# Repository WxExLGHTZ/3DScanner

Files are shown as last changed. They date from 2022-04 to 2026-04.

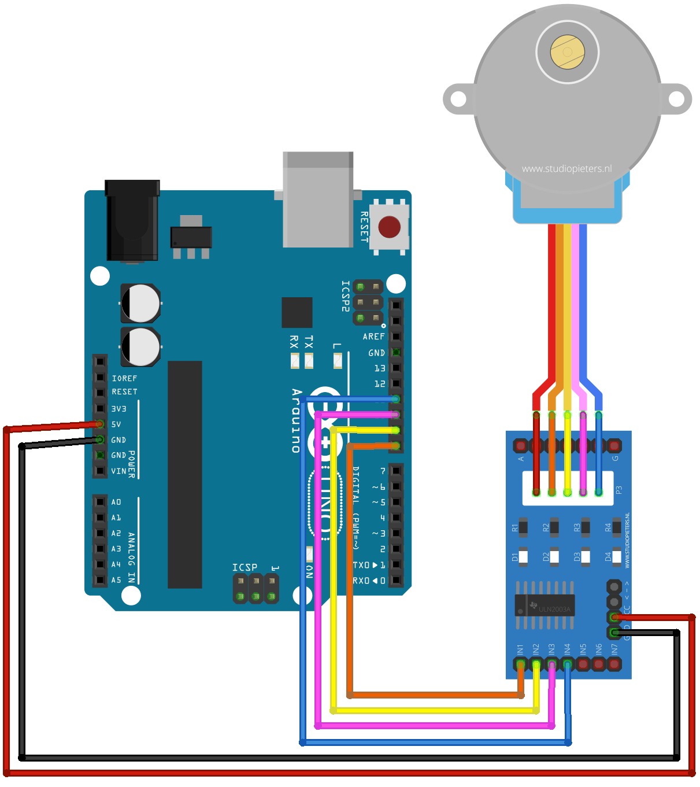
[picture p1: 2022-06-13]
Hardware/Arduino_Steckplan.jpeg

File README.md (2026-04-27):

# 3D Scanner

A desktop application that turns an Intel RealSense depth camera and an Arduino-driven stepper motor turntable into a 3D scanner — capturing RGBD frames from multiple angles, registering them into a unified point cloud via computed rotation-translation matrices, and reconstructing a watertight mesh exported as STL.

## Motivation

Building a 3D scanner from consumer hardware requires solving several non-trivial problems: synchronizing camera capture with turntable rotation, transforming each depth frame into world coordinates based on the current angle, and merging multiple partial point clouds into a single consistent model. This project handles the full pipeline — from raw RGBD frames captured by an Intel RealSense camera through multi-angle point cloud registration to Poisson surface reconstruction — controlled through a PyQt5 desktop interface that lets users configure scan resolution, mesh quality, and hardware settings.

## Features

- Scans physical objects by rotating them on an Arduino-controlled turntable while capturing RGBD frames from an Intel RealSense camera
- Registers point clouds from multiple viewing angles using computed rotation-translation matrices derived from the turntable geometry
- Crops, filters, and denoises point clouds with bounding box constraints and statistical outlier removal
- Reconstructs a watertight triangle mesh from the merged point cloud using Poisson surface reconstruction
- Exports the final model as an STL file, scaled to millimeters
- Displays the point cloud and mesh in an interactive 3D viewer (Open3D)
- Imports existing PLY point cloud files for viewing
- Provides configurable scan parameters: Arduino COM port, step size, frame resolution, and mesh quality settings

## Tech Stack

| Category | Technology |
|---|---|
| Language | Python 3.8.x |
| 3D Processing | Open3D (point clouds, meshing, visualization) |
| Depth Camera | Intel RealSense SDK (pyrealsense2) |
| GUI | PyQt5 |
| Motor Control | Arduino via pyserial (9600 baud) |

## Architecture

The system follows a capture-process-export pipeline driven by the turntable's rotation cycle. The **Arduino** firmware accepts step commands over serial and drives a stepper motor through a 6:1 gear reduction. The **InitializeScan** module configures the RealSense pipeline for aligned color and depth streams and extracts the camera intrinsics. At each rotation step, an RGBD frame is captured and handed to the **ProcessData** module, which converts it to an Open3D point cloud, computes the camera's extrinsic position from the current turntable angle (using trigonometric transformation with known distance and tilt offsets), applies the rotation-translation matrix, crops to a bounding box, and removes outliers. The partial clouds are accumulated into a single registered point cloud. After a full 360° rotation, the **ExportScan** module generates a bottom surface via convex hull sampling, then runs Poisson surface reconstruction with configurable depth and smoothing iterations to produce the final STL mesh.

```
Arduino Turntable ──► RealSense RGBD Capture ──► Point Cloud Conversion
    ──► Extrinsic Transform (angle-based) ──► Registration ──► Poisson Reconstruction ──► STL Export
```

## Getting Started

### Prerequisites

- Windows 
- Python 3.8.x (tested with 3.8.0)
- PyCharm or Visual Studio Code (recommended)
- Intel RealSense D400 series camera
- Arduino with stepper motor (28BYJ-48 + ULN2003 driver, pins 8–11)

### Hardware Setup

Connect the stepper motor driver to Arduino pins 8, 9, 10, 11 and upload the firmware:

```
Upload 3D_scan_neu.ino (or arduino_platform.ino) via the Arduino IDE.
```

> [!NOTE]
> A wiring diagram is provided in `Arduino_Steckplan.jpeg`.

### Installation

1. Clone the repository:
   ```bash
   git clone https://github.com/<your-username>/3d-scanner.git
   cd 3d-scanner/Software
   ```

2. Create and activate a virtual environment:
   ```bash
   python -m venv venv
   .\venv\Scripts\activate
   ```

3. Upgrade pip and install dependencies:
   ```bash
   python -m pip install --upgrade pip
   pip install -r requirements.txt
   ```

> [!NOTE]
> macOS users need to install pyrealsense2 from a separate source:
> `pip install pyrealsense2 -f https://github.com/cansik/pyrealsense2-macosx/releases`

4. Open the project in PyCharm or VS Code and set the interpreter to `venv/Scripts/Python.exe`.

## Usage

1. Place the object on the turntable and connect both the Arduino and the RealSense camera.
2. Run the application:
   ```bash
   python main.py
   ```
3. Click **Settings** to configure the Arduino COM port (default: `COM5`) and scan parameters.
4. Click **Start Scan** — the turntable rotates in steps while the camera captures frames. The status bar shows the current angle. The scan takes less than 1 minute.
5. Click **Show Pointcloud** to inspect the registered point cloud in the 3D viewer.
6. Click **Save STL** to reconstruct the mesh and export it as an STL file.

Alternatively, use **Import** to load an existing `.ply` point cloud file for viewing.

## Authors

- William Eppel
- Mert Karadeniz
- Vinh Thong Trinh
- Habib Ben Khedher

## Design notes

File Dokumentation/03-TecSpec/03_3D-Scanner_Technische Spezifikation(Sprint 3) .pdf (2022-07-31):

### Technische Spezifikation 3D-Scanner mit einer Intel Realsense

© HTW Berlin

# Technische Spezifikation

# HTW Berlin 3D-Scanner mit einer Intel Realsense

Autoren: | Mert Karadeniz, Vinh Thong Trinh, Habib Ben Khedher, William Eppel
Letzte Änderung: 31. Juli 2022
Dateiname: | 03_3D-Scanner_Technische Spezifikation
Version: | 3.0

© HTW Berlin

Copyright

© Mohammad Abuosba

Die Weitergabe, Vervielfältigung oder anderweitige Nutzung dieses Dokumentes oder Teile davon ist unabhängig vom Zweck oder in welcher Form untersagt, es sei denn, die Rechteinhaber/In hat ihre ausdrückliche schriftliche Genehmigung erteilt.

Version Historie

Version | Datum | Verantwortlich | Änderung
1.0 | 02.06.2022 | Alle | Ordnung der Aufgabenbereiche
1.1 | 03.06.2022 | Alle | Einfügung von gegebenen Diagrammen
1.2 | 04.06.2022 | Alle | Systeminfrastruktur
1.3 | 07.06.2022 | Vinh, William | Workflow überarbeitet
1.4 | 07.06.2022 | Mert, Habib | Konstruktion Tech spec.
1.5 | 10.06.2022 | Alle | Konstruktion Tech spec., Beschreibung der Imple-mentierungen überarbeitet
2.0 | 10.06.2022 | Alle | Rechtschreibung, Grammatik
2.1 | 07.07.2022 | Alle | Berichtigung der gegeben Fehler
2.2 | 08.07.2022 | Alle | Hinzufügen neuer Funktionen
2.4 | 11.07.2022 | Alle | Neue Konstruktionszeichnungen eingefügt
3.0 | 31.07.2022 | Alle | Finalisierung

© HTW Berlin | Seite I

## Inhaltsverzeichnis

Abbildungsverzeichnis | II
Verzeichnis vorhandener Dokumente | III

© HTW Berlin | Seite II

## Abbildungsverzeichnis

© HTW Berlin | Seite III

## Verzeichnis vorhandener Dokumente

Alle für die vorliegende Spezifikation ergänzenden Unterlagen müssen hier aufgeführt werden.

Dokument | Autor | Datum
Lastenheft_3d-Scanner.pdf | Team 3 | 25.04.2022
02 Muster_Pflichtenheft.pdf | Team 3 | 23.05.2022
FÜP_SS22.mpp | Team 3 | 23.05.2022

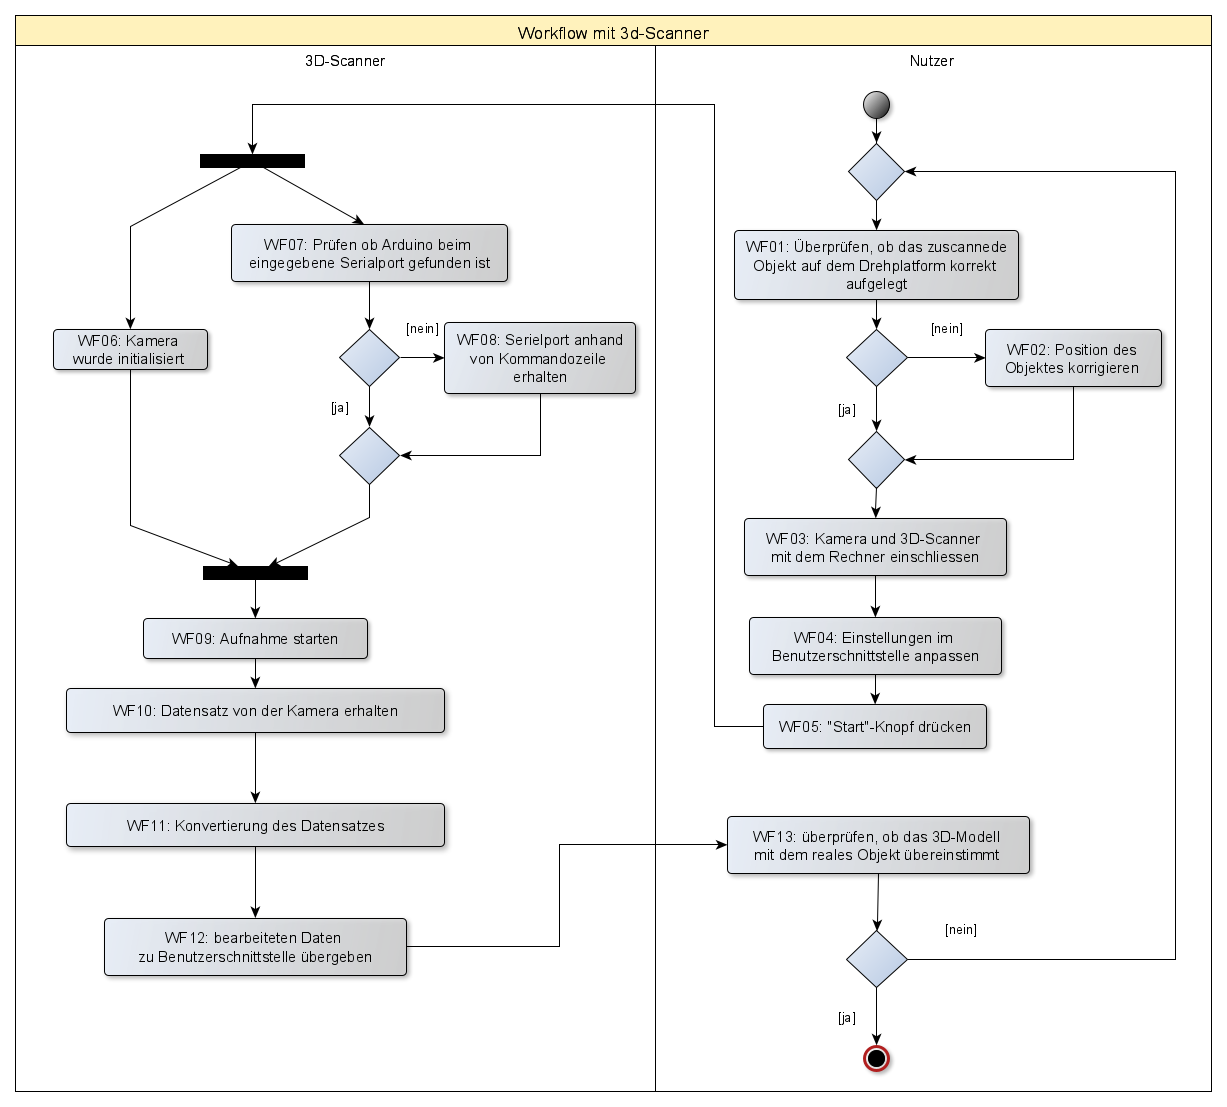
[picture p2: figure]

© HTW Berlin | Seite 1

## 1 Prozessüberblick

## 1.1 Fachlicher Workflow

Im Folgenden wird der fachliche Workflow des Systems dargestellt.

Abbildung 1: Fachlicher Workflow

## 1.2 Technischer Workflow

Im Folgenden wird der technische Workflow des Systems dargestellt.

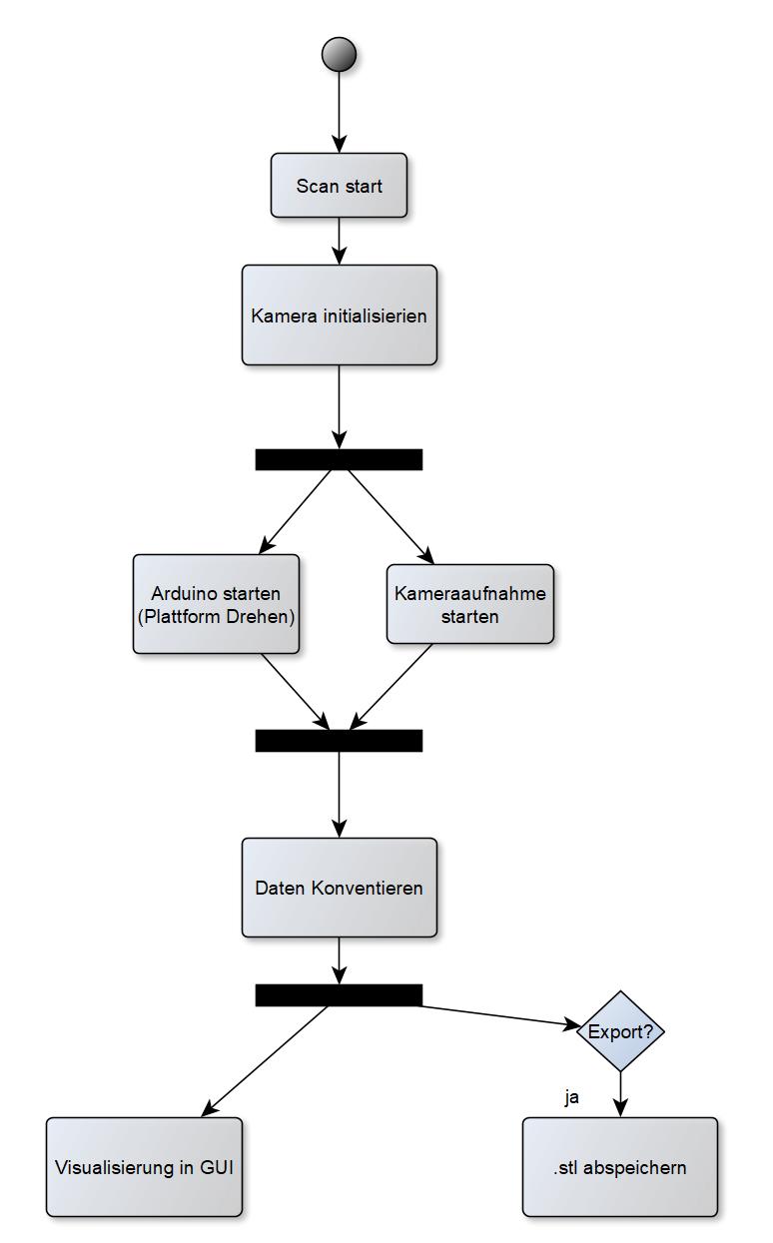
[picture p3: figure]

Abbildung 2: Grober technischer Workflow

Im folgenden wird der technische Workflow im Falle eines Fehlers dargestellt.

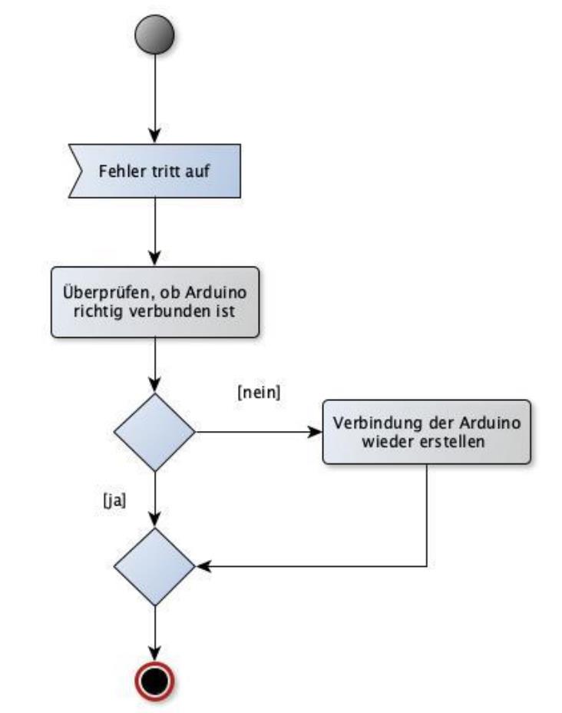
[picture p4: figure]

Abbildung 3: Fehler technischer Workflow

## 2 Technische Spezifikation SW 2.1 Überblick Komponenten

Im folgenden Komponentendiagramm werden die Komponenten der Software dargestellt.

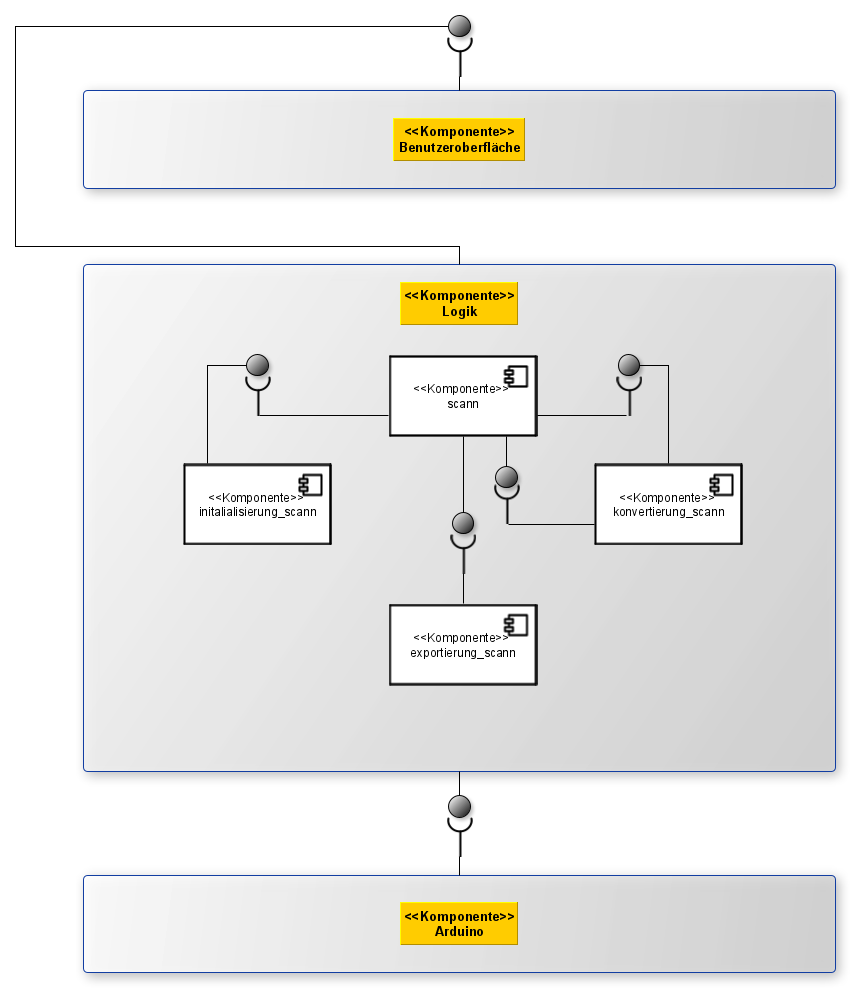
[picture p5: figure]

Abbildung 4: Komponentendiagramm

In der folgenden Tabelle werden die Komponenten ihren Funktionen zugeordnet.

SW-Komponente | Erfasste Funktion aus dem Pflichtenheft
Benutzeroberfläche | F7: Einstellungen Anpassen F8: Standarteinstellungen zurücksetzen UI Funktionen: UI02: Start Scan UI03: Stop Scan UI04: Import UI05: Export UI06: Einstellungen UI07: Beenden UI08: Hilfe
scann | F1: Objekt scannen
Initialiserung_scann | F2: Initialisierung der Kamera F3: Kommunikation mit Arduino F4: Kameraaufnahme starten
konvertierung_scann | F5: Konvertierung/Verarbeitung der Daten
exportierung_scann | F9: Exportierung des Scans als .stl Datei F6: Abspeichern des Scans
Arduino | F10: Rotation des Stepper Motors

Im Folgenden werden die Klassen des Systems in einem Klassendiagramm dargestellt.

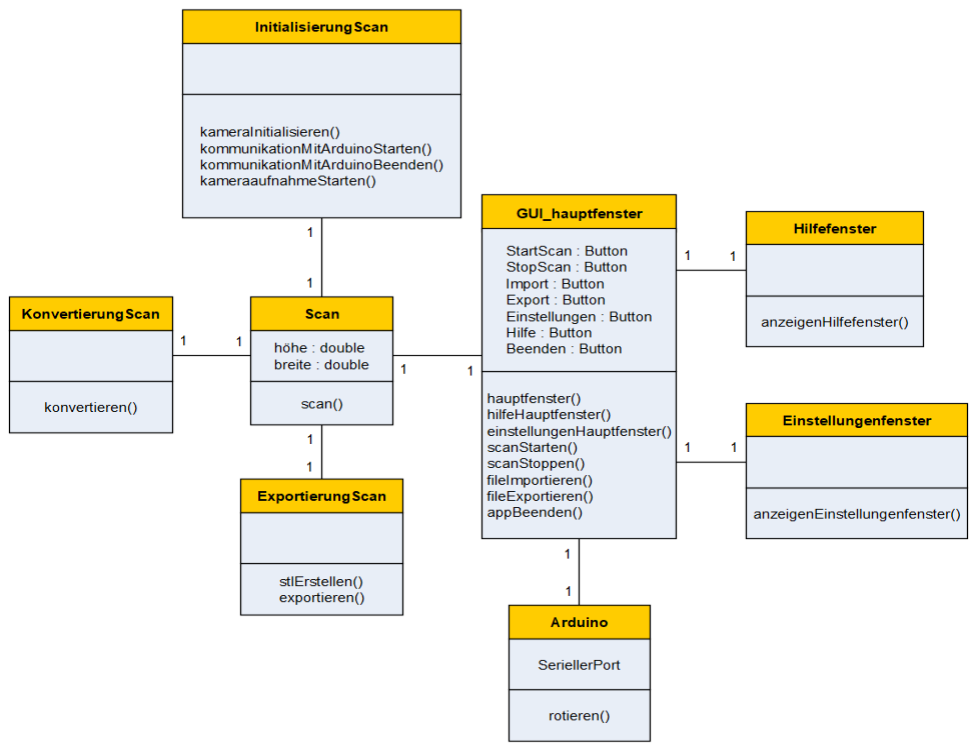
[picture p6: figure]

Abbildung 5: Klassendiagramm

## 2.2 Beschreibung der Implementierung

## 2.2.1 Objekt scannen

Durch die Funktion Objekt scannen, kann ein Scan des Objekts gemacht und daraus ein 3D-Modell erstellt werden.

# | Komponentendetail | Erforderliche Arbeiten

T1 | GUI | • Die Funktion “Scan” soll über den Knopf “Start Scan” ge- startet werden
T2 | Logik | • Die Kamera soll Initialisiert werden • Die Kommunikation mit dem Arduino soll aufgebaut wer-den • Die Kameraaufnahme soll gestartet werden • Die aufgenommenen Daten sollen Konvertiert werden • Das Modell soll erstellt werden
T3 | Arduino | • Nach jedem aufgenommenen Bild soll sich der Schrittmo-tor, der an den Arduino angeschlossen ist, um eine Posi-tion weiterdrehen

## 2.2.2 Kamera initialisieren

Durch die Funktion “Kamera initialisieren” soll die Kamera angeschaltet werden. Es wird geprüft ob eine Kommunikation mit der Kamera besteht.

# | Komponentendetail | Erforderliche Arbeiten

T2 | Logik | • Die Kamera wird eingeschaltet • Die Kommunikation mit der Kamera wird geprüft

## 2.2.3 Drehplattform durch GUI steuern

Durch die Funktion “Drehplattform durch GUI steuern” soll eine Verbindung zwischen der Anwendung und dem Arduino hergestellt werden.

# | Komponentendetail | Erforderliche Arbeiten

T2 | Logik | • Kommunikation mit Arduino soll aufgebaut und überprüft werden
T3 | Arduino | • Arduino wird gestartet

## 2.2.4 Kameraaufnahme starten

Durch die Funktion “Kameraaufnahme starten” sollen mithilfe der Kamera Aufnahmen erstellt werden die anschließend weiterverarbeitet werden sollen.

# | Komponentendetail | Erforderliche Arbeiten

T2 | Logik | • Die Kamera soll in bestimmten Abständen Aufnahmen machen • Die Aufnahmen werden zwischengespeichert

## 2.2.5 Konvertierung der Daten

Durch diese Funktion werden die aufgenommenen Datensätze der Kamera verarbeitet, um sie verwenden zu können.

# | Komponentendetail | Erforderliche Arbeiten

T2 | Logik | • Die Funktion kriegt die aufgenommenen Daten und wan-delt sie in verwendbare Daten um • Die Daten bestehen aus Tiefenbildern die wichtigen Infor-mationen beinhalten • Der entstandene verwendbare Datensatz wird zur GUI weitergegeben • Die Konvertierung der aufgenommenen Datensätze muss implementiert werden

## 2.2.6 Gescanntes Objekt exportieren

Der Scan wird im gewünschten Ort des Nutzers abgespeichert für eine mögliche Weiterverwendung.

# | Komponentendetail | Erforderliche Arbeiten

T1 | GUI | • Die Funktion “Abspeichern des Scans” soll über den Knopf “Export” gestartet werden
T2 | Logik | • Nachdem die Konvertierung zur .stl Datei stattgefunden hat soll die in einem gewünschten Bereich des Nutzers ab-gespeichert werden

## 2.2.7 Einstellungen anpassen

Durch die Funktion “Einstellungen anpassen” können Einstellungen angepasst werden.

# | Komponentendetail | Erforderliche Arbeiten

T1 | GUI | • Die Einstellungen sollen durch die GUI geändert werden

## 2.2.8 Standardeinstellungen zurücksetzen

Die Funktion setzt das Programm wieder auf Werkseinstellungen zurück.

# | Komponentendetail | Erforderliche Arbeiten

T1 | GUI | • Durch einen Knopf in der GUI soll die Funktion “Standar-teinstellungen zurücksetzen” ausgeführt werden • Dadurch werden die Einstellungen zurückgesetzt sowie sie vom Werk aus waren

## 2.2.9 Im Format .stl abspeichern

Das 3D-Model wird in eine .stl Datei konvertiert.

# | Komponentendetail | Erforderliche Arbeiten

T2 | Logik | • In dieser Funktion wird das aufgenommene 3D-Mo-del in eine .stl Datei konvertiert • Durch die Konvertierung in .stl ist eine Weiterverwendung des Models möglich • Die Funktion erhaltet eine Punktwolke und konvertiert diese in .stl

## 2.2.10 Rotation des Steppermotors

Diese Funktion beinhaltet die Rotation des Steppermotors um die Plattform sich rotieren zu lassen.

# | Komponentendetail | Erforderliche Arbeiten

T3 | Arduino | • | Der Arduino spricht den Steppermotor an und lässt ihn in bestimmten Zeit- und Winkelabständen rotieren

## 2.2.11 Portcheck_Arduino

Diese Funktion beinhaltet den Check ob eine Verbindung zu einem Arduino Mikroprozessor besteht.

# | Komponentendetail | Erforderliche Arbeiten

T3 | Logik | • Die Logik versucht einen Arduino anzusprechen, bzw. gibt alle verbundenen Arduinos aus.

## 2.2.12 Portcheck_Cam

Diese Funktion beinhaltet den Check ob eine Verbindung zu einem Realsense Kamera besteht.

# | Komponentendetail | Erforderliche Arbeiten

T3 | Logik | • Die Logik versucht die Realsense Kamera anzuspre-chen und checkt somit ob eine Verbindung besteht

## 2.2.13 Import File

Die Funktion “Import File” bietet die Möglichkeit gegebene .ply Dateien in die GUI zur Ansicht importieren.

# | Komponentendetail | Erforderliche Arbeiten

T3 | GUI | • Durch die GUI wird ein Fenster mit der ausgewählten Datei eröffnet indem man sich das Bauteil anschauen kann

## 2.2.14 Statusmessage

Die Funktion “Statusmessage” ändert die Statusmeldung in der Statusbar, um den User auf dem Laufenden zu halten.

# | Komponentendetail | Erforderliche Arbeiten

T3 | GUI | • Anzeigen der veränderten Statusmeldung.

## 2.3 System Infrastruktur

Die Infrastruktur des Systems besteht aus 4 Komponenten. Der User ist dafür zuständig die Hardware und Software vorzubereiten zum Start, außerdem muss der User die gewünschten Aufforderungen durch die GUI in der Software geben. Die Software nimmt die Aufforderungen des Users an und führt sie aus, dazu ist meist auch eine Kommunikation mit der Hardware nötig, um gegebenenfalls das Drehen der Plattform zu starten. Die Kamera kriegt durch die Software die Anforderungen in bestimmten Abständen Fotos zu schießen, diese werden dann auch zurückgeleitet an die Software.

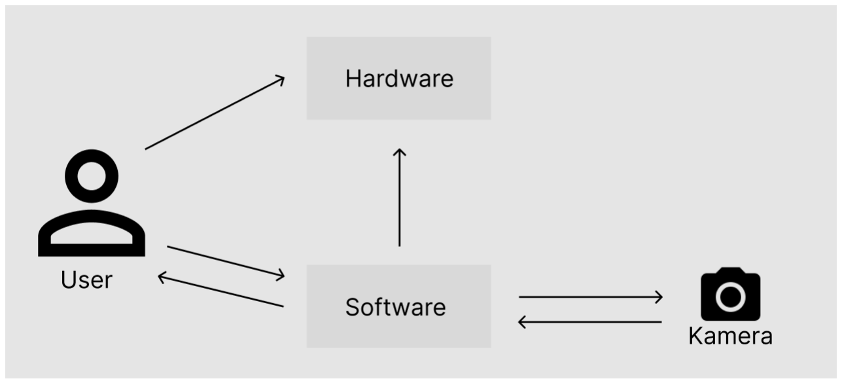
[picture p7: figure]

Abbildung 6: Systeminfrastruktur

## 3 Technische Spezifikation Konstruktion

## 3.1 Baugruppen

Die Baugruppe “3D_Scanner” besteht aus 7 Bauteilen; Gehäuse, Drehplattform Kamerahalter, Zahnrad, Lager, Verbindungsstück und Drehlager. Sie ist die einzige Baugruppe der Konstruktion und ist somit der Hauptbestandteil der Konstruktion. Sie bietet eine Halterung für die Kamera somit die Kamera immer richtig auf das Objekt gerichtet ist, solange das Objekt nicht die Maße des maximal scannbaren Objekts überschreitet. Die Drehplattform befindet sich auf dem Gehäuse, diese bietet eine Fläche für die Platzierung des Objekts. Das Gehäuse bietet Stauplatz für die Hardware und außerdem ist sie auch der Fuß der Konstruktion. Das Verbindungsstück besteht aus Holz und ist die Verbindung zwischen Gehäuse und Kamerahalter, Sie bietet die optimale Distanz von Kamera zum Gehäuse. Das Lager hält das Drehlager und wird im Zentrum des Gehäuses mit zwei Schrauben festgeschraubt. Das Drehlager wird genau zwischen Lager und Plattform platziert somit das Drehlager mit beiden Bauteilen verbunden ist, dadurch wird die Rotation der Plattform ermöglicht. Das Zahnrad wird auf dem Steppermotor platziert, damit es die Drehung auf die Plattform übertragen kann.

Abbildung 7: Technische Zeichnung - Baugruppen

## 3.2 Einzelteile

### Drehplattform

Die Drehplattform ist die Plattform, worauf sich das zu scannende Objekt platziert wird. Die Plattform kann auch als Deckel zum Gehäuse betrachtet werden. Sie dient sowohl als Schutz zur Hardware als auch zur Rotation des Objektes. Sie wird durch eine Kerbe im in der Mitte an den Stepper Motor befestigt.

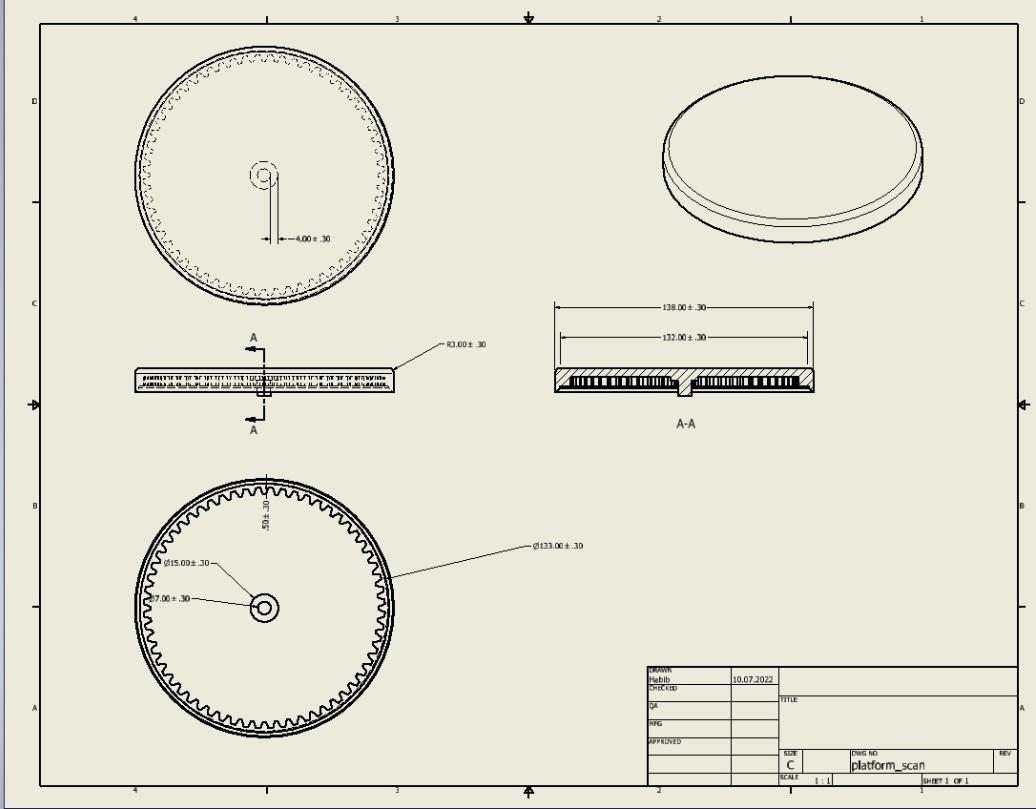
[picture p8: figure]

Abbildung 8: Technische Zeichnung - Drehplattform

### Gehäuse

Das Gehäuse ist der Fuß der Konstruktion. Sie enthält Staufläche für die Hardware und ist auch der Verbindungspunkt aller Bauteile in der Konstruktion. Das Gehäuse bietet einen Verbindungspunkt für die Kamerahalterung durch eine Öffnung an der Wand Seite. Die Hardware wird innerhalb des Gehäuses so platziert, sodass der Motor direkt in die Kerbe der Drehplattform eingeführt werden kann.

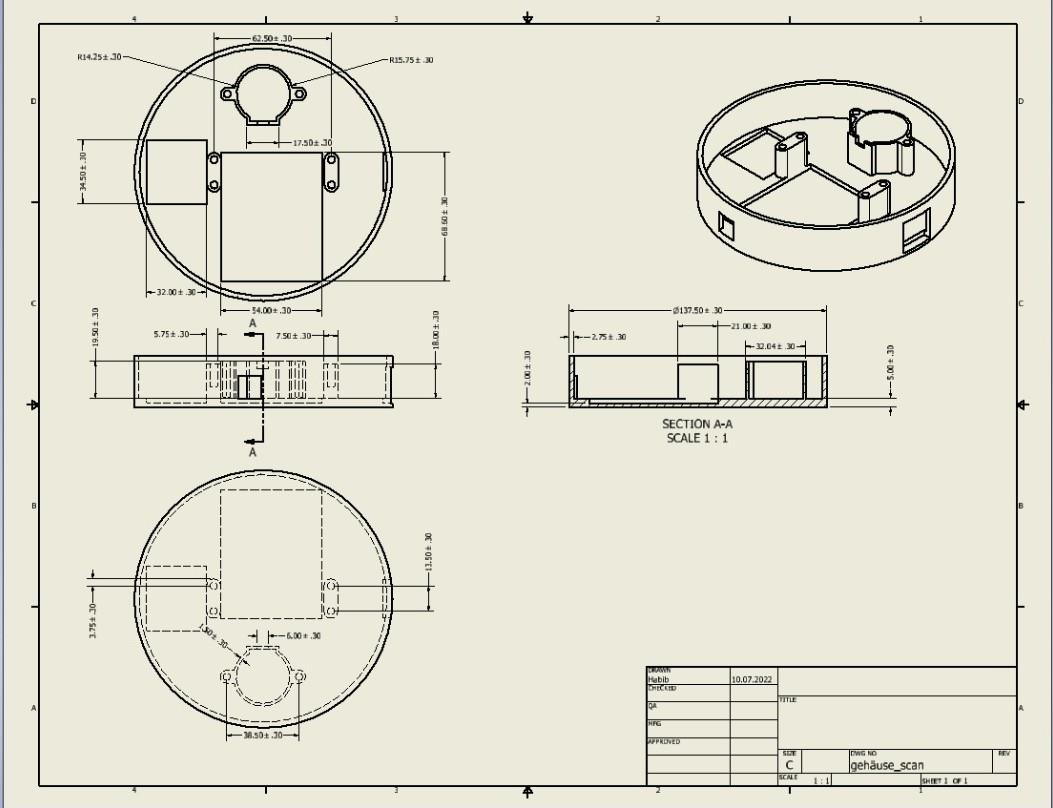
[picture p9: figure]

Abbildung 9: Technische Zeichnung - Gehäuse

### Kamerahalter

Der Kamerahalter ist dazu da die Kamera zu halten. Außerdem ist der Kamerahalter die Verbindung zwischen Kamera und Gehäuse. Durch den Kamerahalter befindet sich die Kamera immer an der optimalen Stelle. Der Kamerahalter wird durch die Öffnung in der Gehäusen Wand eingeführt. Die Kamera wird auf der Spitze des Kamerahalters durch eine Schraube befestigt.

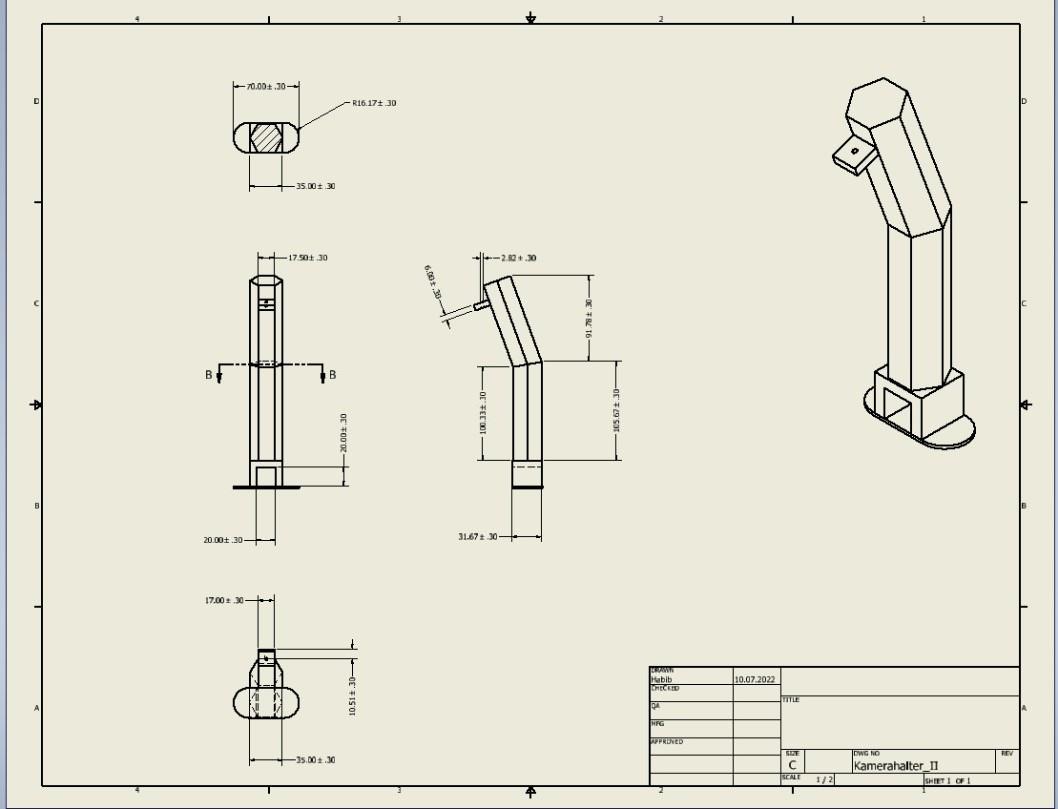
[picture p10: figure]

Abbildung 10: Technische Zeichnung - Kamerahalter

### Lager

Das Lager befindet sich im Gehäusezentrum und bietet eine Verbindung zur Plattform. Durch das Lager wird sie mit der Plattform verbunden und durch zwei Schrauben mit dem Gehäuse. Durch diese Verbindung kann sich die Plattform rotieren und ist dennoch mit dem Gehäuse verbunden. Sie bietet somit auch eine Verschließung der Hardware innerhalb des Gehäuses.

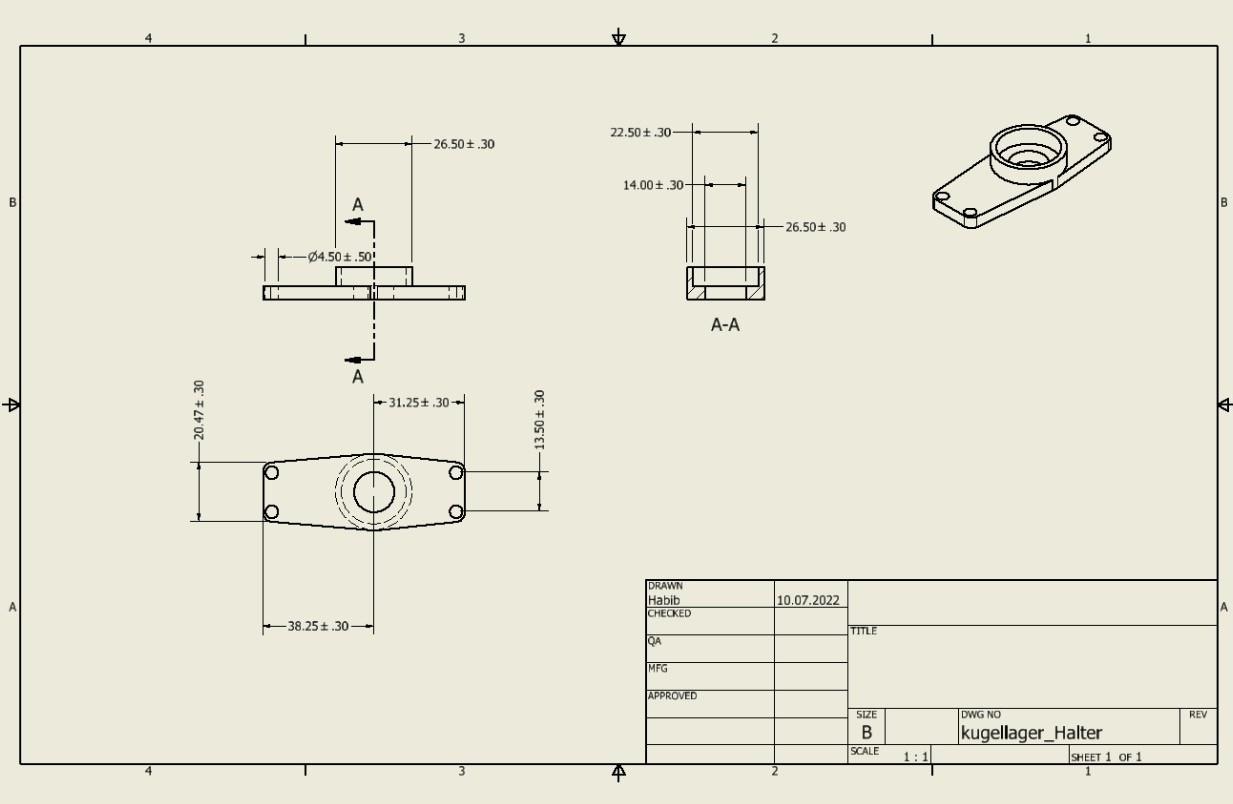
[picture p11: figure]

### Zahnrad

Das Zahnrad befindet sich im Gehäuse auf dem Steppermotor. Sie grenzt am inneren Gewinde der Plattform und ist dadurch mit dem Steppermotor und der Plattform verbunden. Die Drehung des Steppermotors wird durch das Zahnrad auf die Plattform übertragen.

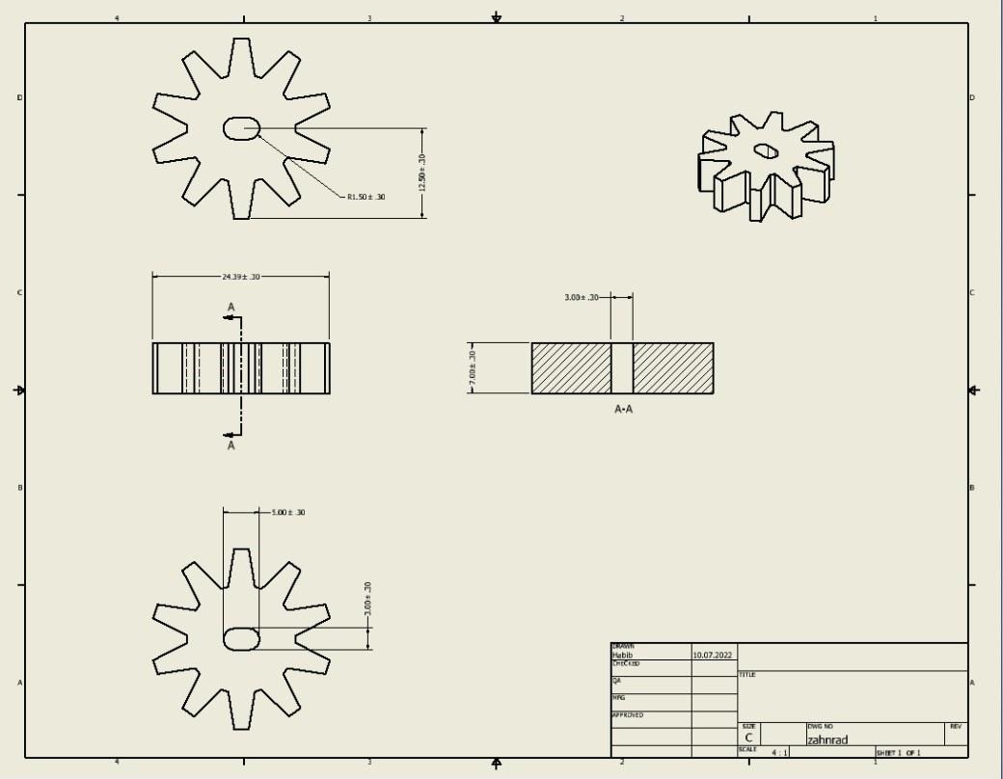
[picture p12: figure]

## 4 Offene Fragen

# | Issue | Status | Owner | Deadline

/ | / | / | / | /

## 5 Modul Abhängigkeiten

1. Programmierung: Die Software wird programmiert
2. Konstruktion: Es wird eine Plattform konstruiert um das Objekt draufzustellen
3. Mechatronik: Es wird ein Mikroprozessor zur Steuerung des Stepper Motors verwendet

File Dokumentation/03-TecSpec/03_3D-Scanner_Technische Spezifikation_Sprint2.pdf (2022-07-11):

### Technische Spezifikation 3D-Scanner mit einer Intel Realsense

© HTW Berlin

# Technische Spezifikation

# HTW Berlin 3D-Scanner mit einer Intel Realsense

Autoren: | Mert Karadeniz, Vinh Thong Trinh, Habib Ben Khedher, William Eppel
Letzte Änderung: 11. Juli 2022
Dateiname: | 03_3D-Scanner_Technische Spezifikation
Version: | 2.5

© HTW Berlin

Copyright

© Mohammad Abuosba

Die Weitergabe, Vervielfältigung oder anderweitige Nutzung dieses Dokumentes oder Teile davon ist unabhängig vom Zweck oder in welcher Form untersagt, es sei denn, die Rechteinhaber/In hat ihre ausdrückliche schriftliche Genehmigung erteilt.

Version Historie

Version | Datum | Verantwortlich | Änderung
1.0 | 02.06.2022 | Alle | Ordnung der Aufgabenbereiche
1.1 | 03.06.2022 | Alle | Einfügung von gegebenen Diagrammen
1.2 | 04.06.2022 | Alle | Systeminfrastruktur
1.3 | 07.06.2022 | Vinh, William | Workflow überarbeitet
1.4 | 07.06.2022 | Mert, Habib | Konstruktion Tech spec.
1.5 | 10.06.2022 | Alle | Konstruktion Tech spec., Beschreibung der Imple-mentierungen überarbeitet
2.0 | 10.06.2022 | Alle | Rechtschreibung, Grammatik
2.1 | 07.07.2022 | Alle | Berichtigung der gegeben Fehler
2.2 | 08.07.2022 | Alle | Hinzufügen neuer Funktionen
2.4 | 11.07.2022 | Alle | Neue Konstruktionszeichnungen eingefügt
2.5 | 11.07.2022 | Alle | Formatierung überarbeitet

© HTW Berlin | Seite I

## Inhaltsverzeichnis

Abbildungsverzeichnis | II
Verzeichnis vorhandener Dokumente | III

© HTW Berlin | Seite II

## Abbildungsverzeichnis

© HTW Berlin | Seite III

## Verzeichnis vorhandener Dokumente

Alle für die vorliegende Spezifikation ergänzenden Unterlagen müssen hier aufgeführt werden.

Dokument | Autor | Datum
Lastenheft_3d-Scanner.pdf | Team 3 | 25.04.2022
02 Muster_Pflichtenheft.pdf | Team 3 | 23.05.2022
FÜP_SS22.mpp | Team 3 | 23.05.2022


© HTW Berlin | Seite 1

## 1 Prozessüberblick

## 1.1 Fachlicher Workflow

Im Folgenden wird der fachliche Workflow des Systems dargestellt.

Abbildung 1: Fachlicher Workflow

## 1.2 Technischer Workflow

Im Folgenden wird der technische Workflow des Systems dargestellt.


Abbildung 2: Grober technischer Workflow

Im folgenden wird der technische Workflow im Falle eines Fehlers dargestellt.


Abbildung 3: Fehler technischer Workflow

## 2 Technische Spezifikation SW 2.1 Überblick Komponenten

Im folgenden Komponentendiagramm werden die Komponenten der Software dargestellt.


Abbildung 4: Komponentendiagramm

In der folgenden Tabelle werden die Komponenten ihren Funktionen zugeordnet.

SW-Komponente | Erfasste Funktion aus dem Pflichtenheft
Benutzeroberfläche | F7: Einstellungen Anpassen F8: Standarteinstellungen zurücksetzen UI Funktionen: UI02: Start Scan UI03: Stop Scan UI04: Import UI05: Export UI06: Einstellungen UI07: Beenden UI08: Hilfe
scann | F1: Objekt scannen
Initialiserung_scann | F2: Initialisierung der Kamera F3: Kommunikation mit Arduino F4: Kameraaufnahme starten
konvertierung_scann | F5: Konvertierung/Verarbeitung der Daten
exportierung_scann | F9: Exportierung des Scans als .stl Datei F6: Abspeichern des Scans
Arduino | F10: Rotation des Stepper Motors

Im Folgenden werden die Klassen des Systems in einem Klassendiagramm dargestellt.

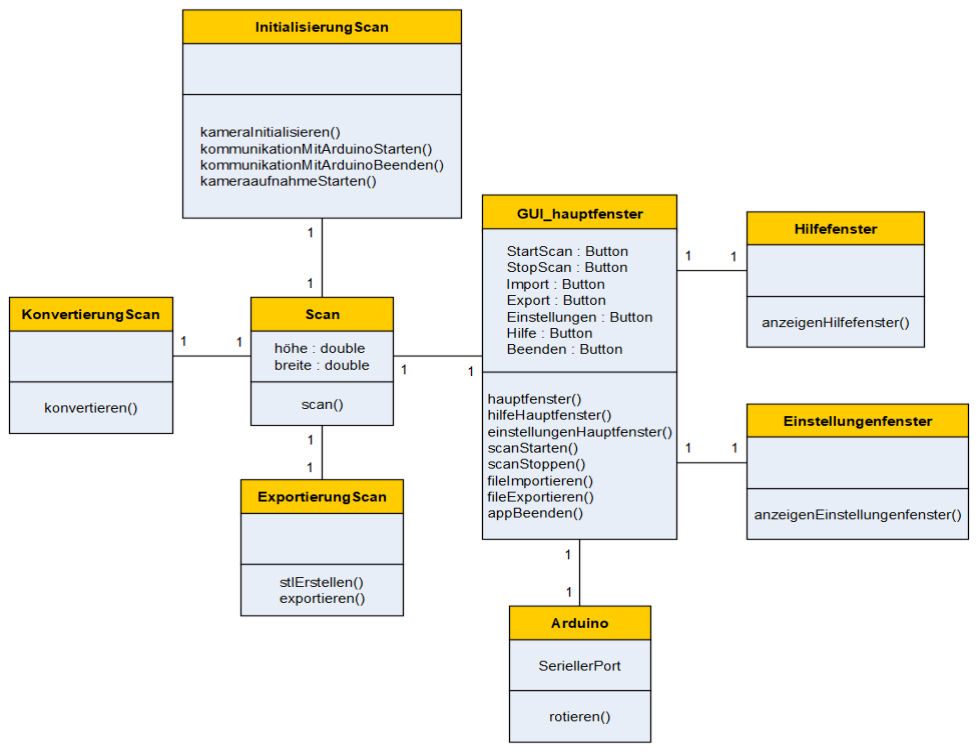
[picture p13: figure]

Abbildung 5: Klassendiagramm

## 2.2 Beschreibung der Implementierung

## 2.2.1 Objekt scannen

Durch die Funktion Objekt scannen, kann ein Scan des Objekts gemacht und daraus ein 3D-Modell erstellt werden.

# | Komponentendetail | Erforderliche Arbeiten

T1 | GUI | • Die Funktion “Scan” soll über den Knopf “Start Scan” ge- startet werden
T2 | Logik | • Die Kamera soll Initialisiert werden • Die Kommunikation mit dem Arduino soll aufgebaut wer-den • Die Kameraaufnahme soll gestartet werden • Die aufgenommenen Daten sollen Konvertiert werden • Das Modell soll erstellt werden
T3 | Arduino | • Nach jedem aufgenommenen Bild soll sich der Schrittmo-tor, der an den Arduino angeschlossen ist, um eine Posi-tion weiterdrehen

## 2.2.2 Kamera initialisieren

Durch die Funktion “Kamera initialisieren” soll die Kamera angeschaltet werden.
Es wird geprüft ob eine Kommunikation mit der Kamera besteht.
# | Komponentendetail | Erforderliche Arbeiten

T2 | Logik | • Die Kamera wird eingeschaltet • Die Kommunikation mit der Kamera wird geprüft

## 2.2.3 Drehplattform durch GUI steuern

Durch die Funktion “Drehplattform durch GUI steuern” soll eine Verbindung zwischen der Anwendung und dem Arduino hergestellt werden.

# | Komponentendetail | Erforderliche Arbeiten

T2 | Logik | • Kommunikation mit Arduino soll aufgebaut und überprüft werden
T3 | Arduino | • Arduino wird gestartet

## 2.2.4 Kameraaufnahme starten

Durch die Funktion “Kameraaufnahme starten” sollen mithilfe der Kamera Aufnahmen erstellt werden die anschließend weiterverarbeitet werden sollen.

# | Komponentendetail | Erforderliche Arbeiten

T2 | Logik | • Die Kamera soll in bestimmten Abständen Aufnahmen machen • Die Aufnahmen werden zwischengespeichert

## 2.2.5 Konvertierung der Daten

Durch diese Funktion werden die aufgenommenen Datensätze der Kamera verarbeitet, um sie verwenden zu können.

# | Komponentendetail | Erforderliche Arbeiten

T2 | Logik | • Die Funktion kriegt die aufgenommenen Daten und wan-delt sie in verwendbare Daten um • Die Daten bestehen aus Tiefenbildern die wichtigen Infor-mationen beinhalten • Der entstandene verwendbare Datensatz wird zur GUI weitergegeben • Die Konvertierung der aufgenommenen Datensätze muss implementiert werden

## 2.2.6 Gescanntes Objekt exportieren

Der Scan wird im gewünschten Ort des Nutzers abgespeichert für eine mögliche Weiterverwendung.

# | Komponentendetail | Erforderliche Arbeiten

T1 | GUI | • Die Funktion “Abspeichern des Scans” soll über den Knopf “Export” gestartet werden
T2 | Logik | • Nachdem die Konvertierung zur .stl Datei stattgefunden hat soll die in einem gewünschten Bereich des Nutzers ab-gespeichert werden

## 2.2.7 Einstellungen anpassen

Durch die Funktion “Einstellungen anpassen” können Einstellungen angepasst werden.

# | Komponentendetail | Erforderliche Arbeiten

T1 | GUI | • Die Einstellungen sollen durch die GUI geändert werden

## 2.2.8 Standardeinstellungen zurücksetzen

Die Funktion setzt das Programm wieder auf Werkseinstellungen zurück.

# | Komponentendetail | Erforderliche Arbeiten

T1 | GUI | • Durch einen Knopf in der GUI soll die Funktion “Standar-teinstellungen zurücksetzen” ausgeführt werden • Dadurch werden die Einstellungen zurückgesetzt sowie sie vom Werk aus waren

## 2.2.9 Im Format .stl abspeichern

Das 3D-Model wird in eine .stl Datei konvertiert.

# | Komponentendetail | Erforderliche Arbeiten

T2 | Logik | • In dieser Funktion wird das aufgenommene 3D-Mo-del in eine .stl Datei konvertiert • Durch die Konvertierung in .stl ist eine Weiterverwendung des Models möglich • Die Funktion erhaltet eine Punktwolke und konvertiert diese in .stl

## 2.2.10 Rotation des Steppermotors

Diese Funktion beinhaltet die Rotation des Steppermotors um die Plattform sich rotieren zu lassen.

# | Komponentendetail | Erforderliche Arbeiten

T3 | Arduino | • Der Arduino spricht den Steppermotor an und lässt ihn in bestimmten Zeit- und Winkelabständen rotieren

## 2.2.11 Portcheck_Arduino

Diese Funktion beinhaltet den Check ob eine Verbindung zu einem Arduino Mikroprozessor besteht.

# | Komponentendetail | Erforderliche Arbeiten

T3 | Logik | • Die Logik versucht einen Arduino anzusprechen, bzw. gibt alle verbundenen Arduinos aus.

## 2.2.12 Portcheck_Cam

Diese Funktion beinhaltet den Check ob eine Verbindung zu einem Realsense Kamera besteht.

# | Komponentendetail | Erforderliche Arbeiten

T3 | Logik | • Die Logik versucht die Realsense Kamera anzuspre-chen und checkt somit ob eine Verbindung besteht

## 2.2.13 Import File

Die Funktion “Import File” bietet die Möglichkeit gegebene .ply Dateien in die GUI zur Ansicht importieren.

# | Komponentendetail | Erforderliche Arbeiten

T3 | GUI | • Durch die GUI wird ein Fenster mit der ausgewählten Datei eröffnet indem man sich das Bauteil anschauen kann

## 2.3 System Infrastruktur

Die Infrastruktur des Systems besteht aus 4 Komponenten. Der User ist dafür zuständig die Hardware und Software vorzubereiten zum Start, außerdem muss der User die gewünschten Aufforderungen durch die GUI in der Software geben. Die Software nimmt die Aufforderungen des Users an und führt sie aus, dazu ist meist auch eine Kommunikation mit der Hardware nötig, um gegebenenfalls das Drehen der Plattform zu starten. Die Kamera kriegt durch die Software die Anforderungen in bestimmten Abständen Fotos zu schießen, diese werden dann auch zurückgeleitet an die Software.

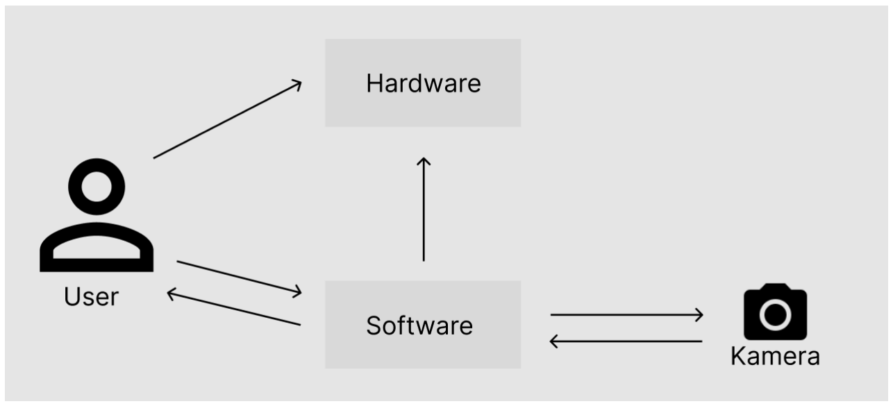
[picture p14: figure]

Abbildung 6: Systeminfrastruktur

## 3 Technische Spezifikation Konstruktion

## 3.1 Baugruppen

Die Baugruppe “3D_Scanner” besteht aus 7 Bauteilen; Gehäuse, Drehplattform Kamerahalter, Zahnrad, Lager, Verbindungsstück und Drehlager. Sie ist die einzige Baugruppe der Konstruktion und ist somit der Hauptbestandteil der Konstruktion. Sie bietet eine Halterung für die Kamera somit die Kamera immer richtig auf das Objekt gerichtet ist, solange das Objekt nicht die Maße des maximal scannbaren Objekts überschreitet. Die Drehplattform befindet sich auf dem Gehäuse, diese bietet eine Fläche für die Platzierung des Objekts. Das Gehäuse bietet Stauplatz für die Hardware und außerdem ist sie auch der Fuß der Konstruktion. Das Verbindungsstück besteht aus Holz und ist die Verbindung zwischen Gehäuse und Kamerahalter, Sie bietet die optimale Distanz von Kamera zum Gehäuse. Das Lager hält das Drehlager und wird im Zentrum des Gehäuses mit zwei Schrauben festgeschraubt. Das Drehlager wird genau zwischen Lager und Plattform platziert somit das Drehlager mit beiden Bauteilen verbunden ist, dadurch wird die Rotation der Plattform ermöglicht. Das Zahnrad wird auf dem Steppermotor platziert, damit es die Drehung auf die Plattform übertragen kann.

## 3.2 Einzelteile

### Drehplattform

Die Drehplattform ist die Plattform, worauf sich das zu scannende Objekt platziert wird. Die Plattform kann auch als Deckel zum Gehäuse betrachtet werden. Sie dient sowohl als Schutz zur Hardware als auch zur Rotation des Objektes. Sie wird durch eine Kerbe im in der Mitte an den Stepper Motor befestigt.


Abbildung 7: Technische Zeichnung - Drehplattform

### Gehäuse

Das Gehäuse ist der Fuß der Konstruktion. Sie enthält Staufläche für die Hardware und ist auch der Verbindungspunkt aller Bauteile in der Konstruktion. Das Gehäuse bietet einen Verbindungspunkt für die Kamerahalterung durch eine Öffnung an der Wand Seite. Die Hardware wird innerhalb des Gehäuses so platziert, sodass der Motor direkt in die Kerbe der Drehplattform eingeführt werden kann.


Abbildung 8: Technische Zeichnung - Gehäuse

### Kamerahalter

Der Kamerahalter ist dazu da die Kamera zu halten. Außerdem ist der Kamerahalter die Verbindung zwischen Kamera und Gehäuse. Durch den Kamerahalter befindet sich die Kamera immer an der optimalen Stelle. Der Kamerahalter wird durch die Öffnung in der Gehäusen Wand eingeführt. Die Kamera wird auf der Spitze des Kamerahalters durch eine Schraube befestigt.


Abbildung 9: Technische Zeichnung - Kamerahalter

### Lager

Das Lager befindet sich im Gehäusezentrum und bietet eine Verbindung zur Plattform. Durch das Lager wird sie mit der Plattform verbunden und durch zwei Schrauben mit dem Gehäuse. Durch diese Verbindung kann sich die Plattform rotieren und ist dennoch mit dem Gehäuse verbunden. Sie bietet somit auch eine Verschließung der Hardware innerhalb des Gehäuses.


Abbildung 10: Technische Zeichnung - Kugellagerhalter

### Zahnrad

Das Zahnrad befindet sich im Gehäuse auf dem Steppermotor. Sie grenzt am inneren Gewinde der Plattform und ist dadurch mit dem Steppermotor und der Plattform verbunden. Die Drehung des Steppermotors wird durch das Zahnrad auf die Plattform übertragen.


Abbildung 11: Technische Zeichnung - Zahnrad

## 4 Offene Fragen

# | Issue | Status | Owner | Deadline

/ | / | / | / | /

## 5 Modul Abhängigkeiten

1. Programmierung: Die Software wird programmiert
2. Konstruktion: Es wird eine Plattform konstruiert um das Objekt draufzustellen
3. Mechatronik: Es wird ein Mikroprozessor zur Steuerung des Stepper Motors verwendet

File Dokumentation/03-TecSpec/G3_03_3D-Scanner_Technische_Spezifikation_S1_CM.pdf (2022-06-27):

### Technische Spezifikation 3D-Scanner mit einer Intel Realsense

© HTW Berlin

# Technische Spezifikation

# HTW Berlin 3D-Scanner mit einer Intel Realsense

Autor: | Mert Karadeniz, Vinh Thong Trinh, Habib Ben Khedher, William Eppel
Letzte Änderung: 13. Juni 2022
Dateiname: | 03_3D-Scanner_Technische Spezifikation
Version: | 2.0

© HTW Berlin

Copyright

© Mohammad Abuosba

Die Weitergabe, Vervielfältigung oder anderweitige Nutzung dieses Dokumentes oder Teile davon ist unabhängig vom Zweck oder in welcher Form untersagt, es sei denn, die Rechteinhaber/In hat ihre ausdrückliche schriftliche Genehmigung erteilt.

Version Historie

Version | Datum | Verantwortlich | Änderung
1.0 | 02.06.2022 | Alle | Ordnung der Aufgabenbereiche
1.1 | 03.06.2022 | Alle | Einfügung von gegebenen Diagrammen
1.2 | 04.06.2022 | Alle | Systeminfrastruktur
1.3 | 07.06.2022 | Vinh, William | Workflow überarbeitet
1.4 | 07.06.2022 | Mert, Habib | Konstruktion Tech spec.
1.5 | 10.06.2022 | Alle | Konstruktion Tech spec., Beschreibung der Imple-mentierungen überarbeitet
2.0 | 10.06.2022 | Alle | Rechtschreibung, Grammatik
2.0 | 13.06.2022 | Alle | Finalisierung

© HTW Berlin

## Inhaltsverzeichnis

Abbildungsverzeichnis | I
Tabellenverzeichnis | II
Verzeichnis vorhandener Dokumente | III

© HTW Berlin | Seite I

## Abbildungsverzeichnis

© HTW Berlin | Seite II

## Tabellenverzeichnis

© HTW Berlin | Seite III

## Verzeichnis vorhandener Dokumente

Alle für die vorliegende Spezifikation ergänzenden Unterlagen müssen hier aufgeführt werden.

Dokument | Autor | Datum
Lastenheft_3d-Scanner.pdf | Team 3 | 25.04.2022
02 Muster_Pflichtenheft.pdf | Team 3 | 23.05.2022
FÜP_SS22.mpp | Team 3 | 23.05.2022

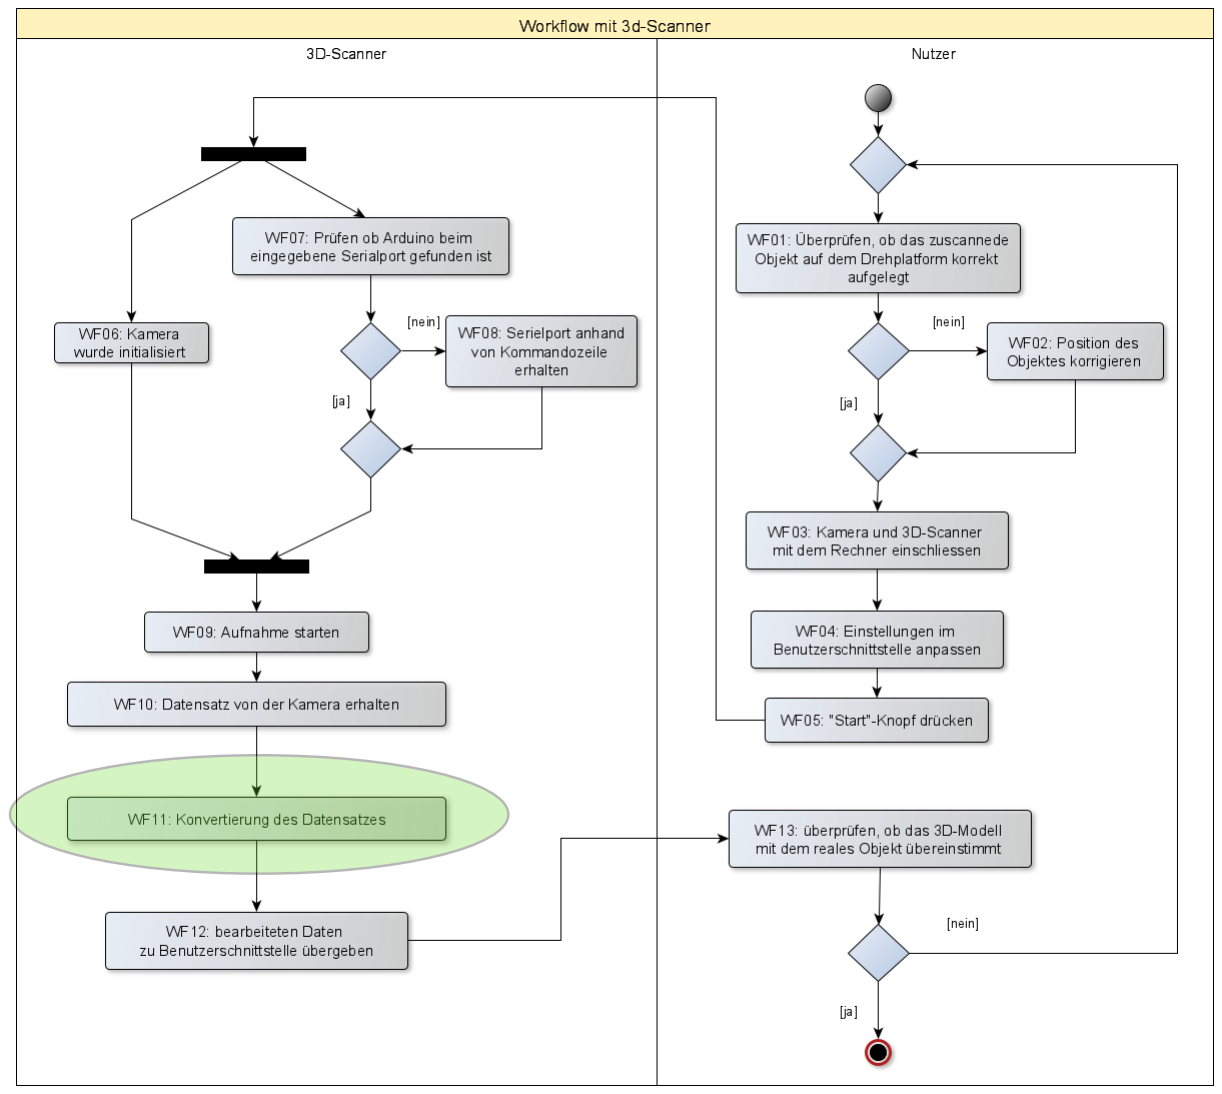
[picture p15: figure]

© HTW Berlin | Seite 1

## 1 Prozessüberblick

## 1.1 Fachlicher Workflow

Im Folgenden wird der fachliche Workflow des Systems dargestellt.

Abbildung 1: Fachlicher Workflow

## 1.2 Technischer Workflow

Im Folgenden wird der technische Workflow des Systems dargestellt.


Abbildung 2: Grober technischer Workflow

Im folgenden wird der technische Workflow im Falle eines Fehlers dargestellt.


Abbildung 3: Fehler technischer Workflow

## 2 Technische Spezifikation SW 2.1 Überblick Komponenten

Im folgenden Komponentendiagramm werden die Komponenten der Software dargestellt.


Abbildung 4: Komponentendiagramm

In der folgenden Tabelle werden die Komponenten ihren Funktionen zugeordnet.

SW-Komponente | Erfasste Funktion aus dem Pflichtenheft
Benutzeroberfläche | F7: Einstellungen Anpassen F8: Standarteinstellungen zurücksetzen UI Funktionen: UI01: 3D-Viewer UI02: Start Scan UI03: Stop Scan UI04: Import UI05: Export UI06: Einstellungen UI07: Beenden UI08: Hilfe
Scan | F1: Objekt scannen
Initialiserung_scan | F2: Initialisierung der Kamera F3: Kommunikation mit Arduino F4: Kameraaufnahme starten
Konvertierung_scan | F5: Konvertierung/Verarbeitung der Daten
Exportierung_scan | F9: Exportierung des Scans als .stl Datei F6: Abspeichern des Scans
Arduino | F10: Rotation des Stepper Motors

Tabelle 1: Zuordnung der Komponenten

Im Folgenden werden die Klassen des Systems in einem Klassendiagramm dargestellt.

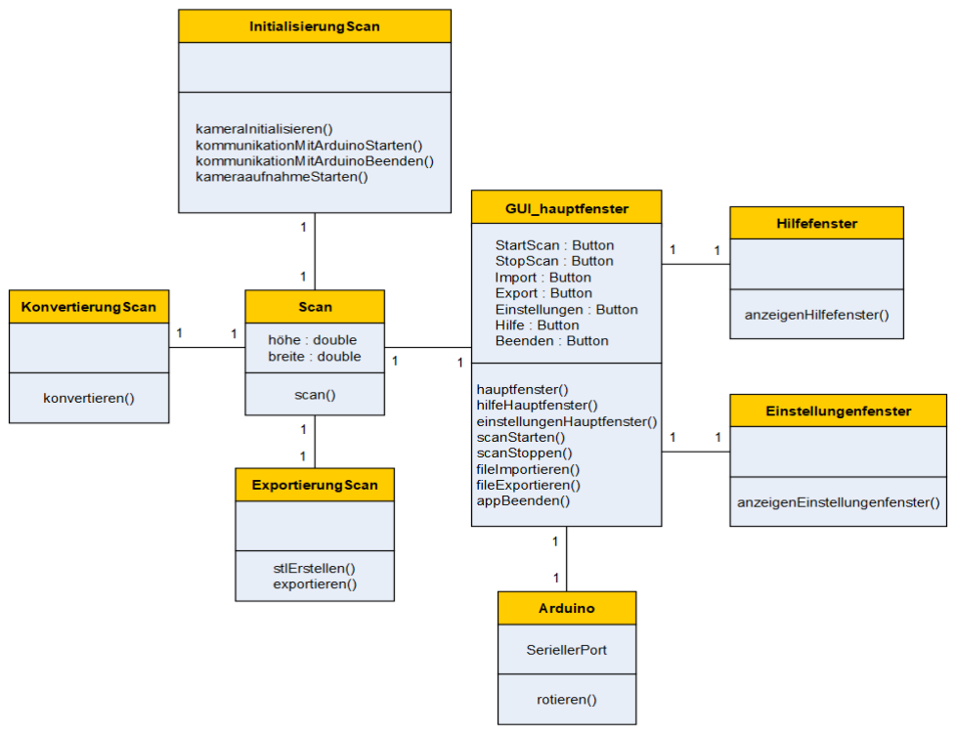
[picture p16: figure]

Abbildung 5: Klassendiagramm

## 2.2 Beschreibung der Implementierung

## 2.2.1 Scan

Durch die Funktion Scan, kann ein Scan des Objekts gemacht und daraus ein 3d-Modell erstellt werden.

# | Komponentendetail | Erforderliche Arbeiten

T1 | GUI | • Die Funktion “Scan” soll über den Knopf “StartScan” ge-startet werden
T2 | Logik | • Die Kamera soll Initialisiert werden • Die Kommunikation mit dem Arduino soll aufgebaut wer- den • Die Kameraaufnahme soll gestartet werden • Die aufgenommenen Daten sollen Konvertiert werden • Das Modell soll erstellt werden
T3 | Arduino | • Nach jedem aufgenommenen Bild soll sich der Schrittmo- tor, der an den Arduino angeschlossen ist, um eine Posi- tion weiterdrehen

Tabelle 2: Beschreibung von der Funktion „Scan“

## 2.2.2 Initialisierung der Kamera

Durch die Funktion “Kamera initialisieren” soll die Kamera angeschaltet werden. Es wird geprüft ob eine Kommunikation mit der Kamera besteht.

# | Komponentendetail | Erforderliche Arbeiten

T2 | Logik | • Die Kamera wird eingeschaltet • Die Kommunikation mit der Kamera wird geprüft

Tabelle 3: Beschreibung der Funktion „Kamera Initialisierung"

## 2.2.3 Kommunikation mit Arduino

Durch die Funktion “Kommunikation mit Arduino” soll eine Verbindung zwischen der Anwendung und dem Arduino hergestellt werden.

# | Komponentendetail | Erforderliche Arbeiten

T2 | Logik | • Kommunikation mit Arduino soll aufgebaut und überprüft werden
T3 | Arduino | • Arduino wird gestartet

Tabelle 4: Beschreibung von der Funktion "Kommunikation mit Arduino"

## 2.2.4 Kameraaufnahme starten

Durch die Funktion “Kameraaufnahme starten” sollen mithilfe der Kamera Aufnahmen erstellt werden die anschließend weiterverarbeitet werden sollen.

# | Komponentendetail | Erforderliche Arbeiten

T2 | Logik | • Die Kamera soll in bestimmten Abständen Aufnahmen machen • Die Aufnahmen werden zwischengespeichert

Tabelle 5: Beschreibung von der Funktion "Kameraaufnahme starten"

## 2.2.5 Konvertierung/Verarbeitung der Daten

Durch diese Funktion werden die aufgenommenen Datensätze der Kamera verarbeitet, um sie verwenden zu können.

# | Komponentendetail | Erforderliche Arbeiten

T2 | Logik | • Die Funktion kriegt die aufgenommenen Daten und wan-delt sie in verwendbare Daten um • Die Daten bestehen aus Tiefenbildern die wichtigen Infor-mationen beinhalten • Der entstandene verwendbare Datensatz wird zur GUI weitergegeben • Die Konvertierung der aufgenommenen Datensätze muss implementiert werden

Tabelle 6: Beschreibung der Funktion "Konvertierung der Daten"

## 2.2.6 Abspeichern des Scans

Der Scan wird im gewünschten Ort des Nutzers abgespeichert für eine mögliche Weiterverwendung.

# | Komponentendetail | Erforderliche Arbeiten

T1 | GUI | • Die Funktion “Abspeichern des Scans” soll über den Knopf “Export” gestartet werden
T2 | Logik | • Nachdem die Konvertierung zur .stl Datei stattgefunden hat soll die in einem gewünschten Bereich des Nutzers ab-gespeichert werden

Tabelle 7: Beschreibung von der Funktion "Abspeichern des Scans"

## 2.2.7 Einstellungen anpassen

Durch die Funktion Einstellungen anpassen können Einstellungen angepasst werden.

# | Komponentendetail | Erforderliche Arbeiten

T1 | GUI | • Die Einstellungen sollen durch die GUI geändert werden

Tabelle 8: Beschreibung der Funktion "Einstellungen Anpassen"

## 2.2.8 Standardeinstellungen zurücksetzen

Die Funktion führt das Programm wieder auf Werkseinstellungen.

# | Komponentendetail | Erforderliche Arbeiten

T1 | GUI | • Durch einen Knopf in der GUI soll die Funktion “Standar-teinstellungen zurücksetzen” ausgeführt werden • Dadurch werden die Einstellungen zurückgesetzt sowie sie vom Werk aus waren

Tabelle 9: Beschreibung von der Funktion "Standarteinstellungen zurücksetzen"

## 2.2.9 Exportierung des Scans in .stl Datei

Das 3D-Model wird in eine .stl Datei konvertiert.

# | Komponentendetail | Erforderliche Arbeiten

T2 | Logik | • In dieser Funktion wird das aufgenommene 3D-Mo-del in eine .stl Datei konvertiert • Durch die Konvertierung in .stl ist eine Weiterverwendung des Models möglich • Die Funktion erhaltet eine Punktwolke und konvertiert diese in .stl

Tabelle 10: Beschreibung der Funktion "Exportierung des Scans"

## 2.2.10 Rotation des Stepper Motors

Diese Funktion beinhaltet die Rotation des Stepper Motors um die Plattform sich rotieren zu lassen.

# | Komponentendetail | Erforderliche Arbeiten

T3 | Arduino | • Der Arduino spricht den Stepper Motor an und lässt ihn in bestimmten Zeit- und Winkelabständen rotieren

Tabelle 11: Beschreibung der Funktion "Rotation des Stepper Motors"

## 2.3 System Infrastruktur

Die Infrastruktur des Systems besteht aus 4 Komponenten. Der User ist dafür zuständig die Hardware und Software vorzubereiten zum Start, außerdem muss der User die gewünschten Aufforderungen durch die GUI in der Software geben. Die Software nimmt die Aufforderungen des Users an und führt sie aus, dazu ist meist auch eine Kommunikation mit der Hardware nötig, um gegebenenfalls das Drehen der Plattform zu starten. Die Kamera kriegt durch die Software die Anforderungen in bestimmten Abständen Fotos zu schießen, diese werden dann auch zurückgeleitet an die Software.

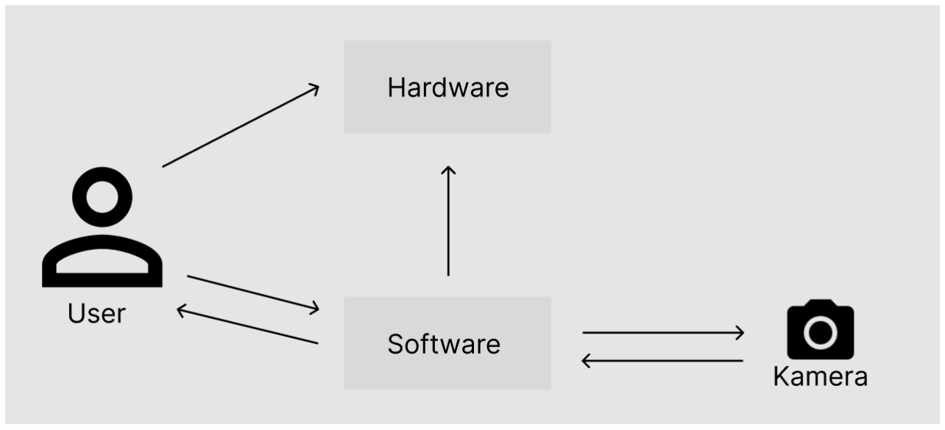
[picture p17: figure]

Abbildung 6: Systeminfrastruktur

## 3 Technische Spezifikation Konstruktion

## 3.1 Baugruppen

Die Baugruppe “3D_Scanner” besteht aus drei Bauteilen; Gehäuse, Drehplattform und Kamerahalter. Sie ist die einzige Baugruppe der Konstruktion und ist somit der Hauptbestandteil der Konstruktion. Sie bietet eine Halterung für die Kamera somit die Kamera immer richtig auf das Objekt gerichtet ist, solange das Objekt nicht die Maße des maximal scannbaren Objekts überschreitet. Die Drehplattform befindet sich auf dem Gehäuse, diese bietet eine Fläche für die Platzierung des Objekts. Das Gehäuse bietet Stauplatz für die Hardware und außerdem ist sie auch der Fuß der Konstruktion.

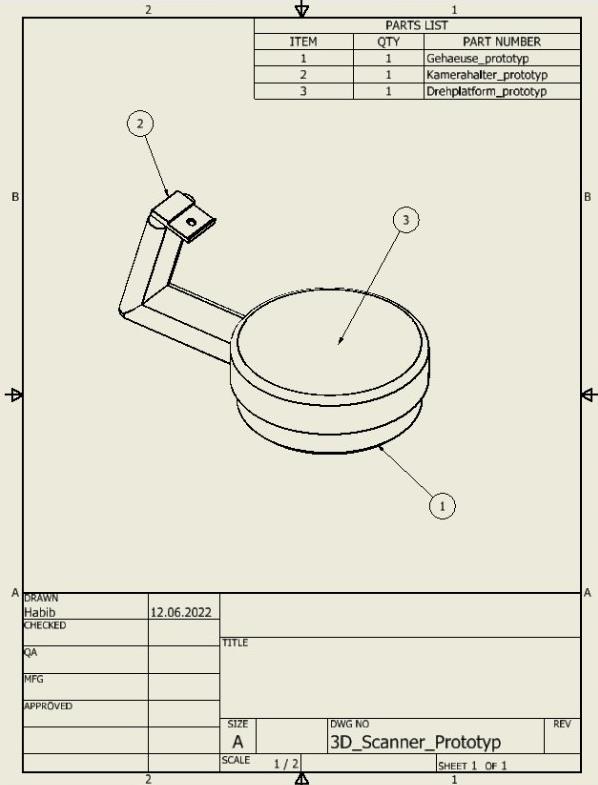
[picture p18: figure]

Abbildung 7: Technische Zeichnung - Baugruppen

## 3.2 Einzelteile

### Drehplattform

Die Drehplattform ist die Plattform worauf sich das zu scannende Objekt platziert wird. Die Plattform kann auch als Deckel zum Gehäuse betrachtet werden. Sie dient sowohl als Schutz zur Hardware als auch zur Rotation des Objektes. Sie wird durch eine Kerbe im in der Mitte an den Stepper Motor befestigt.

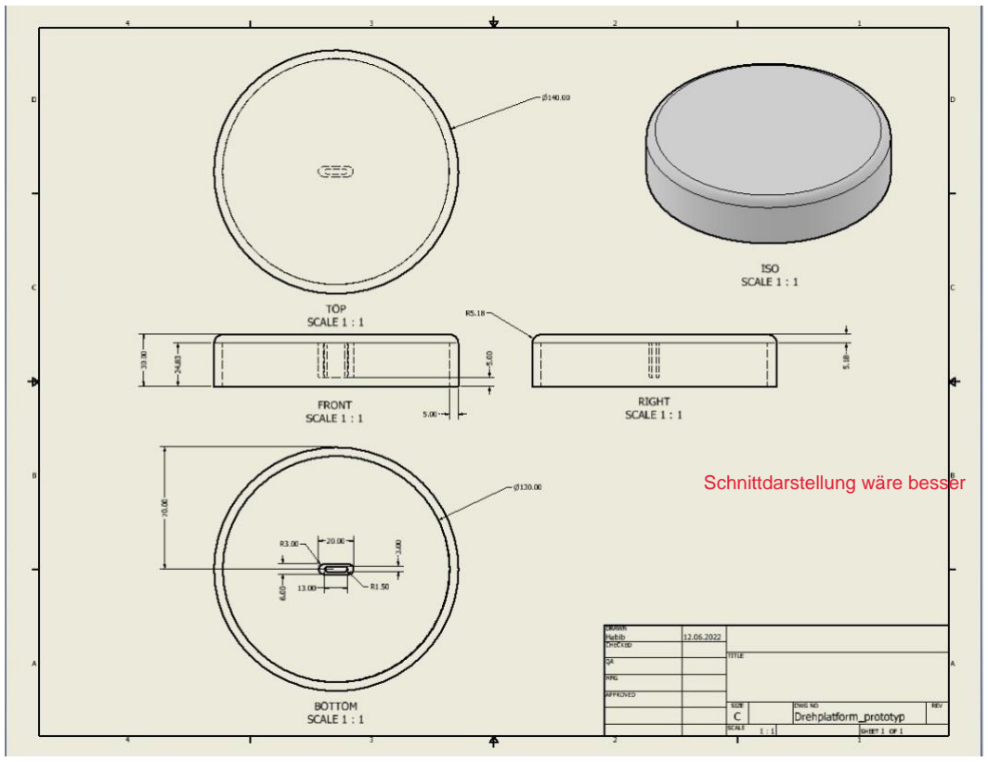
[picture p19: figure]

Abbildung 8: Technische Zeichnung - Drehplattform

### Gehäuse

Das Gehäuse ist der Fuß der Konstruktion. Sie enthält Staufläche für die Hardware und ist auch der Verbindungspunkt aller Bauteile in der Konstruktion. Das Gehäuse bietet einen Verbindungspunkt für die Kamerahalterung durch eine Öffnung an der Wand Seite. Die Hardware wird innerhalb des Gehäuses so platziert, sodass der Motor direkt in die Kerbe der Drehplattform eingeführt werden kann.

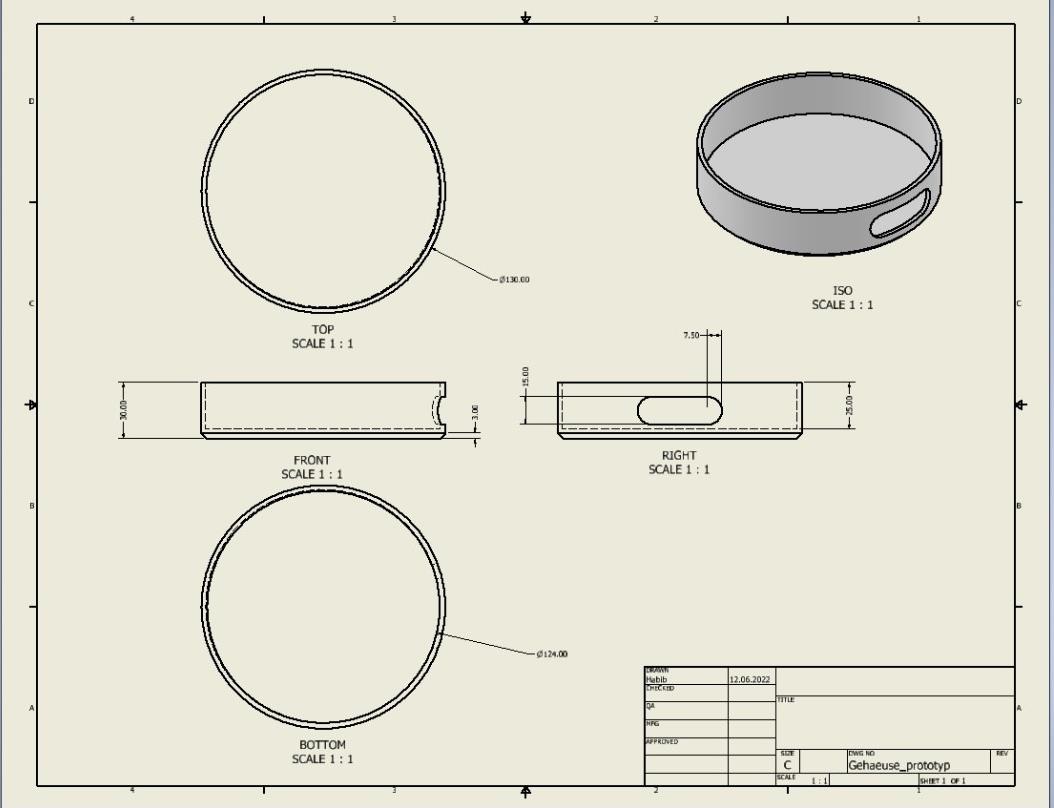
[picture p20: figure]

Abbildung 9: Technische Zeichnung - Gehäuse

### Kamerahalter

Der Kamerahalter ist dazu da die Kamera zu halten. Außerdem ist der Kamerahalter die Verbindung zwischen Kamera und Gehäuse. Durch den Kamerahalter befindet sich die Kamera immer an der optimalsten Stelle. Der Kamerahalter wird durch die Öffnung in der Gehäusen Wand eingeführt. Die Kamera wird auf der Spitze des Kamerahalters durch eine Schraube befestigt.

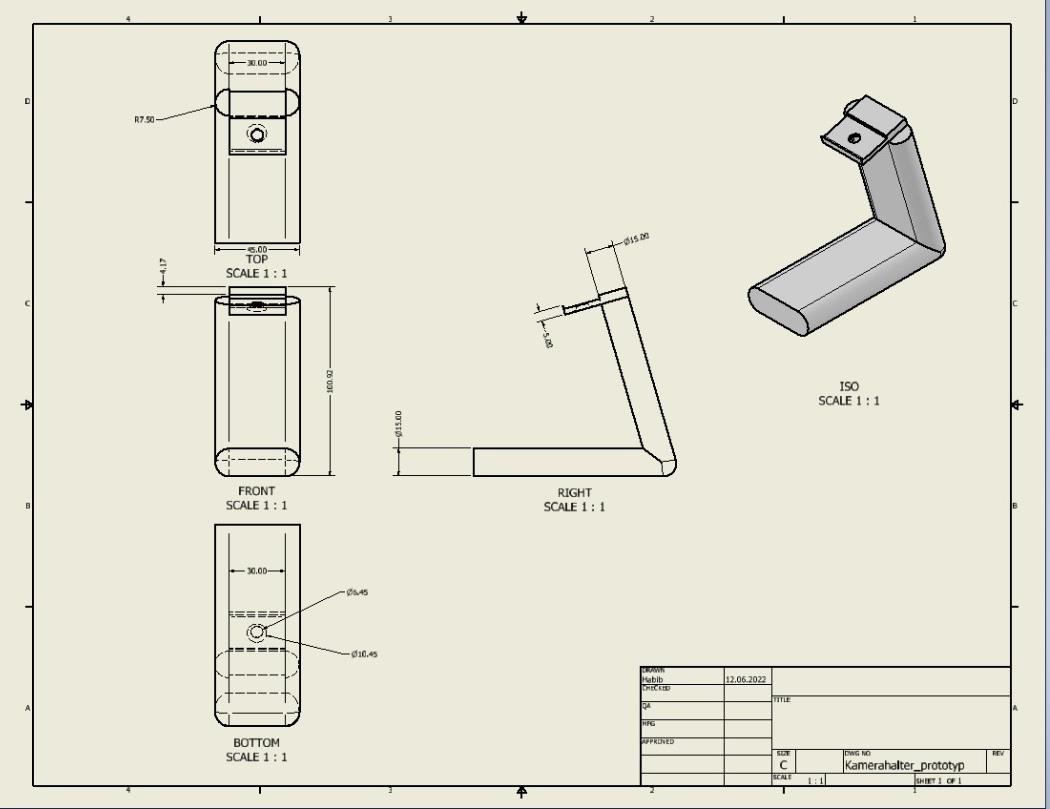
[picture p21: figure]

Abbildung 10: Technische Zeichnung - Kamerahalter

## 4 Offene Fragen

# | Issue | Status | Owner | Deadline

/ | / | / | / | /

## 5 Modul Abhängigkeiten

1. Programmierung: Die Software wird programmiert
2. Konstruktion: Es wird eine Plattform konstruiert um das Objekt draufzustellen
3. Mechatronik: Es wird ein Mikroprozessor zur Steuerung des Stepper Motors verwendet

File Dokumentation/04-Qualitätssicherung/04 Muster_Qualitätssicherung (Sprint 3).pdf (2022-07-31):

### Muster Qualitätssicherung

### 3D-Scanner mit einer Intel Realsense

© HTW Berlin

# Qualitätssicherung

# HTW Berlin 3D-Scanner mit einer Intel Realsense

Autoren: | Mert Karadeniz, Vinh Thong Trinh, Habib Ben Khedher, William Eppel
Letzte Änderung: 31. Juli 2022
Dateiname: | 04 Muster_Qualitätssicherungg.docx
Version: | 3.0

© HTW Berlin

Copyright

© Mohammad Abuosba

Die Weitergabe, Vervielfältigung oder anderweitige Nutzung dieses Dokumentes oder Teile davon ist unabhängig vom Zweck oder in welcher Form untersagt, es sei denn, die Rechteinhaber/In hat ihre ausdrückliche schriftliche Genehmigung erteilt.

Version Historie

Version | Datum | Verantwortlich | Änderung
1.0 | 11.06.2022 | Alle | Initiale Dokumenterstellung
1.1 | 12.06.2022 | Alle | Erweiterung
2.0 | 13.06.2022 | Alle | Finalisierung
3.0 | 31.07.2022 | Alle | Erweiterung + Finaliesierung

## Inhaltsverzeichnis

Verzeichnis vorhandener Dokumente | II

## Verzeichnis vorhandener Dokumente

Alle für die vorliegende Spezifikation ergänzenden Unterlagen müssen hier aufgeführt werden

Dokument | Autor | Datum
Lastenheft_3d-Scanner.pdf | Team 3 | 25.04.2022
02 Muster_Pflichtenheft.pdf | Team 3 | 23.05.2022
FÜP_SS22.mpp | Team 3 | 23.05.2022

## 1 Testfälle

## 1.1 Testfall 1: GUI – Erkennung & Verbindung der Hardware

Testfall | Beschreibung
Testfall-Nummer | 00001
Testart | Funktionstest
Zu testender Geschäftsprozess/ Zu testende Funktionsgruppe | Auf Buttonklick – Arduino <-> GUI Auf Buttonklick – Intel Realsense <-> GUI
Testziel | Validieren, ob die GUI sich mit der Kamera und dem Arduino sich ver-bindet.
Testvoraussetzungen | • Python 3.8 muss bereits installiert sein • PyQt5 muss installiert sein • Pyrealsense2 • Pyserial
Testfalldaten | GUI Backend_arduino Main
Erwartetes Verhalten | Die Erkennung und Verbindung der Hardware funktionieren einwandfrei. Es wird zuerst nach der Erkennung gecheckt und dann wird die GUI mit der Hardware verbunden.
Testergebnis | X Bestanden | □ Nicht Bestanden
Fehlerkategorie | □ Leicht | □ Mittel | □ Schwerwiegend

Bemerkung

Tester Kunde | Tester Auftragnehmer | Datum
| | 31.07.2022
Tabelle 1: Testfall 1 – Erkennung & Verbindung der Hardware

## 1.2 Testfall 2: Importierung & Visualisierung von Punktwolken (.ply)

Testfall | Beschreibung
Testfall-Nummer | 00002
Testart | Funktionstest

Zu testender Geschäftsprozess/
Zu testende Funktionsgruppe

GUI – Import Knopf

Testziel | Validieren, ob die Importierung von .ply Dateien funktionieren
Testvoraussetzungen | • Python 3.8 muss bereits installiert sein
- PyQt5 muss installiert sein
- Open3D muss installiert sein
Testfalldaten | GUI
Erwartetes Verhalten | Es kann mit QFileDialog eine .ply Datei ausgewählt werden und sie wird
anschließend angezeigt.
Testergebnis | X Bestanden | □ Nicht Bestanden
Fehlerkategorie | □ Leicht □ Mittel □ Schwerwiegend

Bemerkung

Tester Kunde | Tester Auftragnehmer | Datum 31.07.2022

Tabelle 2: Testfall 2 – Dimension der GUI

## 1.3 Testfall 3: Dimension der Konstruktion

Testfall | Beschreibung
Testfall-Nummer | 00003
Testart | Integrationstest
Zu testender Geschäftsprozess/ Zu testende Funktionsgruppe | Zusammenbau
Testziel | Validieren, ob alle Teile zusammengebaut werden können
Testvoraussetzungen | Drucken von 2. Prototyp
Testfalldaten | 3D-gedruckte-Bauteile
Erwartetes Verhalten | • | Alle Bauteile sollen zusammenpassen
- Die Drehplattform soll sich reibungsfrei umdrehen
- Kamerahalter soll nicht zu hochgestellt und nicht zu nah zur
| | Drehplattform sein
Testergebnis | x Bestanden □ Nicht Bestanden
Fehlerkategorie | □ Leicht □ Mittel □ Schwerwiegend

Bemerkung
- Dimension der Drehplattform wurde angepasst
- Kamera Halter ist jetzt verschiebbar
Tester Kunde | Tester Auftragnehmer | Datum
| | 31.07.2022

Tabelle 3: Testfall 3 – Dimension der Konstruktion

## 1.4 Testfall 4: Analyse von gedruckten Bauteilen

Testfall | Beschreibung
Testfall-Nummer | 00004
Testart | Materialtest
Zu testender Geschäftsprozess/ Zu testende Funktionsgruppe | Druckinspektion
Testziel | Validieren, ob die Bauteile gut gedruckt sind.
Testvoraussetzungen | Drucken von 2. Prototyp
Testfalldaten | 3D-gedruckte-Bauteile
Erwartetes Verhalten | • Kleine und nah-zu-einander Schichten • Keine Dehnung von Bauteilen • Homogener Druck
Testergebnis | X Bestanden □ Nicht Bestanden
Fehlerkategorie | X Leicht □ Mittel □ Schwerwiegend

Bemerkung

Tester Kunde | Tester Auftragnehmer | Datum 31.07.2022

Tabelle 4: Testfall 4 – Analyse von gedruckten Bauteilen

## 1.5 Testfall 5: Drehung des Stepper Motors

Testfall | Beschreibung
Testfall-Nummer | 00005
Testart | Belastungstest
Zu testender Geschäftsprozess/ Zu testende Funktionsgruppe | Arduino Code
Testziel | Validieren, ob der Stepper Motor sich anhand von serieller Kommuni-kation sich dreht
Testvoraussetzungen | Implementierung und Verbindung von Arduino und Stepper Motor
Testfalldaten | Der Stepper Motor soll seriell gesteuert werden
Erwartetes Verhalten | Stepper Motor dreht sich nur wenn das Programm ihm serielle Buch-staben kommuniziert
Testergebnis | X Bestanden □ Nicht Bestanden
Fehlerkategorie | □ Leicht □ Mittel □ Schwerwiegend

Bemerkung

Tester Kunde | Tester Auftragnehmer | Datum 31.07.2022

Tabelle 5: Testfall 5 – Drehung des Stepper Motors

## 1.6 Testfall 6: Erfassung von 3D-Punktwolken unter einer Minute

Testfall | Beschreibung
Testfall-Nummer | 00006
Testart | Funktionstest
Zu testender Geschäftsprozess/ Zu testende Funktionsgruppe | Arduino Code und Logik
Testziel | Validieren, ob die 3D-Punktwolken den realen Objekt beschreibt
Testvoraussetzungen | Implementierung und Verbindung von Arduino und Kamera
Testfalldaten | Objekt auf dem Drehplatform
Erwartetes Verhalten | Nach dem Ablauf des Prozesses sollte das resultierendes 3D-Punktwolken ähnlich zum Objekt sein
Testergebnis | □ Bestanden X Nicht Bestanden
Fehlerkategorie | □ Leicht x Mittel □ Schwerwiegend
Bemerkung | • Ein Bug aus der Kalibrierung der Kamera mit der Logik • Erfassung erfolgt unter einer Minute
Tester Kunde | Tester Auftragnehmer | Datum 31.07.2022

Tabelle 6: Testfall 6 – Drehung des Stepper Motors

## 2 Testprotokoll

Testfall-Nr. | Datum | Status | Fehler-kategorie | Datum 2. Lauf | Status 2. Lauf
01 | 31.07.22 | bestanden
02 | 31.07.22 | bestanden
03 | 31.07.22 | bestanden
04 | 31.07.22 | bestanden
05 | 31.07.22 | bestanden
06 | 31.07.22 | Nicht bestanden | 2
Tabelle 7: Testprotokoll

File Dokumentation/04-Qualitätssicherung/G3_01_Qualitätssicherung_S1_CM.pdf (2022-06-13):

### Qualitätssicherung

3D-Scanner mit einer Intel Realsense

Ó HTW Berlin

# Qualitätssicherung

# HTW Berlin 3D-Scanner mit einer Intel Realsense

Autor: | Mert Karadeniz, Vinh Thong Trinh, Habib Ben Khedher, William Eppel
Letzte Änderung: 13. Juni 2022
Dateiname: | 04 Muster_Qualitätssicherungg.docx
Version: | 2.0

Ó HTW Berlin

Copyright

Ó Mohammad Abuosba

Die Weitergabe, Vervielfältigung oder anderweitige Nutzung dieses Dokumentes oder Teile davon ist unabhängig vom Zweck oder in welcher Form untersagt, es sei denn, die Rechteinhaber/In hat ihre ausdrückliche schriftliche Genehmigung erteilt.

Version Historie

Version | Datum | Verantwortlich | Änderung
1.0 | 11.06.2022 | Alle | Initiale Dokumenterstellung
1.1 | 12.06.2022 | Alle | Erweiterung
2.0 | 13.06.2022 | Alle | Finalisierung

## Inhaltsverzeichnis

Tabellenverzeichnis | III

## Verzeichnis vorhandener Dokumente

Alle für die vorliegende Spezifikation ergänzenden Unterlagen müssen hier aufgeführt werden

Dokument | Autor | Datum
Lastenheft_3d-Scanner.pdf | Team 3 | 25.04.2022
02 Muster_Pflichtenheft.pdf | Team 3 | 23.05.2022
FÜP_SS22.mpp | Team 3 | 23.05.2022

## Tabellenverzeichnis

## 1 Testfälle

## 1.1 Testfall 1: GUI – Benutzbarkeit der GUI

Testfall | Beschreibung
Testfall-Nummer | 00001
Testart | Funktionstest
Zu testender Geschäftsprozess/
Zu testende Funktionsgruppe

Klicken der Buttons

Testziel | Validieren, ob die jeweiligen Buttons funktionieren, mit den zugehörigen Methoden
Testvoraussetzungen | • Python 3.8 muss bereits installiert sein • PyQt5 muss installiert sein
Testfalldaten | GUI - Buttons
Erwartetes Verhalten | Alle Buttons der GUI sind einwandfrei nutzbar, bei jedem klick der But-tons kommt ein Feedback.
Testergebnis | X Bestanden □ Nicht Bestanden
Fehlerkategorie | □ Leicht □ Mittel □ Schwerwiegend

Bemerkung

Tester Kunde | Tester Auftragnehmer | Datum
| | 11.06.2022
Tabelle 1: Testfall 1 - Benutzbarkeit der GUI

## 1.2 Testfall 2: Dimension der GUI

Testfall | Beschreibung
Testfall-Nummer | 00002
Testart | Funktionstest
Zu testender Geschäftsprozess/ Zu testende Funktionsgruppe | GUI – Fenster Größe
Testziel | Validieren, ob Veränderungen der GUI auch die Buttons Position und Größen der Buttons ändern bzw. ob die überhaupt veränderbar ist.
Testvoraussetzungen | • Python 3.8 muss bereits installiert sein
- PyQt5 muss installiert sein
Testfalldaten | GUI
Erwartetes Verhalten | Die GUI sollte erst gar nicht veränderbar sein. Die GUI soll eine gefixte
| Größe besitzen.
Testergebnis | X Bestanden | □ Nicht Bestanden
Fehlerkategorie | □ Leicht | □ Mittel | □ Schwerwiegend

Bemerkung

Tester Kunde | Tester Auftragnehmer | Datum
| | 11.06.2022
Tabelle 2: Testfall 2 – Dimension der GUI

## 1.3 Testfall 3: Dimension der Konstruktion

Testfall | Beschreibung
Testfall-Nummer | 00003
Testart | Integrationstest
Zu testender Geschäftsprozess/ Zu testende Funktionsgruppe | Zusammenbau
Testziel | Validieren, ob alle Teile zusammengebaut werden können
Testvoraussetzungen | Drücken von 1. Prototyp
Testfalldaten | 3D-gedrückte-Bauteile
Erwartetes Verhalten | • Alle Bauteile sollen zusammenpassen • Die Drehplattform soll sich reibungsfrei umdrehen • Kamerahalter soll nicht zu hochgestellt und nicht zu nah zum Drehplattform sein
Testergebnis | □ Bestanden X Nicht Bestanden
Fehlerkategorie | □ Leicht □ Mittel X Schwerwiegend
Bemerkung | • Drehplattform kann sich nicht bewegen sobald diese einge- setzt ist (breiter und auch kurzer machen) • Kamera Halter ist zu nah und zu tiefgestellt
Tester Kunde | Tester Auftragnehmer | Datum
| | 12.06.2022
Tabelle 3: Testfall 3 – Dimension der Konstruktion

## 1.4 Testfall 4: Analyse von gedruckten Bauteilen

Testfall | Beschreibung
Testfall-Nummer | 00004
Testart | Materialtest
Zu testender Geschäftsprozess/ Zu testende Funktionsgruppe | Druckinspektion
Testziel | Validieren, ob die Bauteile gut gedruckt sind.
Testvoraussetzungen | Drucken von 1. Prototyp
Testfalldaten | 3D-gedruckte-Bauteile
Erwartetes Verhalten | • Kleine und nah-zu-einander Schichten • Keine Dehnung von Bauteilen • Homogener Druck
Testergebnis | □ Bestanden X Nicht Bestanden
Fehlerkategorie | □ Leicht □ Mittel X Schwerwiegend
Bemerkung | • Temperatur beim Druck soll niedriger eingestellt um Dehnung der Bauteile zu vermeiden • Keine Homogener Druck
Tester Kunde | Tester Auftragnehmer | Datum 12.06.2022

Tabelle 4:Testfall 4 – Analyse von gedruckten Bauteilen

## 1.5 Testfall 5: Drehung des Stepper Motors

Testfall | Beschreibung
Testfall-Nummer | 00005
Testart | Belastungstest
Zu testender Geschäftsprozess/ Zu testende Funktionsgruppe | Stepper Motor Code
Testziel | Validieren, ob der Stepper Motor sich unendlich dreht
Testvoraussetzungen | Implementierung und Verbindung von Arduino und Stepper Motor
Testfalldaten | Der Stepper Motor soll sich für Minimum eine Stunde drehen
Erwartetes Verhalten | Stepper Motor dreht sich für eine Stunde.
Testergebnis | X Bestanden □ Nicht Bestanden
Fehlerkategorie | □ Leicht □ Mittel □ Schwerwiegend
Bemerkung
Tester Kunde | Tester Auftragnehmer | Datum 12.06.2022

Tabelle 5: Testfall 5 – Drehung des Stepper Motors

## 2 Testprotokoll

Testfall-Nr. | Datum | Status | Fehler-kategorie | Datum 2. Lauf | Status 2. Lauf
01 | 11.06.22 | bestanden
02 | 11.06.22 | bestanden
03 | 12.06.22 | nicht bestanden | 3
04 | 12.06.22 | nicht bestanden | 3
05 | 12.06.22 | bestanden
Tabelle 6: Testprotokoll

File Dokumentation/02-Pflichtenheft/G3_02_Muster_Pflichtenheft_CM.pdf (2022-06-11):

### Pflichtenheft

3D-Scanner mit einer Intel RealSense

© HTW Berlin

# Pflichtenheft

## HTW Berlin 3D-Scanner mit einer Intel RealSense

Autor: | Vinh Thong Trinh, Mert Karadeniz, Habib Ben Khedher, William Eppel
Letzte Änderung: 24. Mai 2022
Dateiname: | 02 Muster_Pflichtenheft.docx
Version: | 1.0

Copyright

© Mohammad Abuosba

Die Weitergabe, Vervielfältigung oder anderweitige Nutzung dieses Dokumentes oder Teile davon ist unabhängig vom Zweck oder in welcher Form untersagt, es sei denn, die Rechteinhaber/In hat ihre ausdrückliche schriftliche Genehmigung erteilt.

© HTW Berlin

Version Historie

Version | Datum | Verantwortlich | Änderung
0.1 | 05.05.2022 | Vinh Thong Trinh, Mert Karadeniz, Habib Ben Khedher, William Eppel | Einleitung, Überblick
0.2 | 18.05.2022 | Vinh Thong Trinh, Mert Karadeniz, Habib Ben Khedher, William Eppel | Funktionalitäten, Use-Case, Workflow
0.3 | 23.05.2022 | Vinh Thong Trinh, Mert
Karadeniz, | Habib | Ben
Khedher, William Eppel

Optimiert, überarbeitet, Rechtschreibung und Grammatik

1.0 | 25.05.2022 | Vinh Thong Trinh, Mert
Karadeniz, | Habib | Ben
Khedher, William Eppel

Abgabe

I

## Inhaltsverzeichnis

Abbildungsverzeichnis | II
Tabellenverzeichnis | III
Verzeichnis vorhandener Dokumente | IV

II

## Abbildungsverzeichnis

III

## Tabellenverzeichnis

Tabelle 1: Verzeichnis vorhandener Dokumente | IV

IV

## Verzeichnis vorhandener Dokumente

Alle für die vorliegende Spezifikation ergänzenden Unterlagen müssen hier aufgeführt werden.

Dokument | Autor | Datum
Lastenheft | HTW-Berlin | 26.04.2022
Tabelle 1: Verzeichnis vorhandener Dokumente

© HTW Berlin | Seite

## 1 Überblick

Im Projekt soll ein 3D-Scanner entwickelt werden, der diverse Objekte, die bestimmte Voraussetzungen erfüllen, digitalisieren kann, sodass die erstellten digitalen Kopien weiterverwendet werden können. Die Schwierigkeit besteht darin, ein Produkt zu schaffen, das einen niedrigen Einkaufspreis sowie niedrige Instandhaltungskosten aufweist und zudem Kompakt und leicht zu transportieren ist. Die Schnittstelle der Hardware und Software besteht aus einem Arduino Mikroprozessor. Die Daten, die mithilfe der Software zur Digitalisierung des Objektes führen, werden durch die Intel Realsense Kamera Model D415 aufgenommen. Die aufgenommenen Daten liegen in Form von Tiefenbildern vor.

Das Produkt soll aus 3D - gedruckten Einzelteilen (Material) bestehen, um ein bestimmtes Gewicht nicht zu überschreiten. Durch intelligente Konzipierung der Konstruktion, soll geboten werden, dass der Nutzer allein die Instandhaltung gewährleisten kann. Der niedrige Einkaufspreis zeichnet sich durch die Nutzung einer einzigen Kamera aus.

## 2 Hauptziele

In der folgenden Tabelle sind die Hauptziele des Projektes mit den jeweiligen Implementationen aufgeführt.

# | Ziel | Beschreibung der Implementation

1 | Erkennung eines Objektes | Intel Realsense D415(Tiefenkamera) Python Package PyRealSense2
2 | Anzeigen des 3D-Objektes | Python Package Open3D und PIL
3 | Ansteuerung der Hardware | Python Package PySerial
5 | Ansteuerung Schrittmotor | Arduino Uno
6 | Export des 3D-Objektes (.stl) | Python Package Open3D

Tabelle 2: Hauptziele mit Beschreibung

## 3 Annahmen und Abgrenzungen

In der folgenden Tabelle sind unsere Annahmen nummeriert beschrieben worden.

# | Annahmen

1 | Besitz eines Rechners mit USB-Anschluss
2 | Die Software ist auf dem Rechner installiert
3 | Bilderkennung über Intel Realsense
4 | Objekt darf keine spiegelnde Oberfläche besitzen
5 | Objekt ist max. groß wie eine Tasse, 8cm Durchmesser, 8,5cm Höhe
6 | Das Gewicht des Objektes überschreitet nicht 350 Gramm

Tabelle 3: fachliche und technische Annahmen

In der folgenden Tabelle sind unsere Abgrenzungen nummeriert beschrieben worden.

# | Abgrenzungen (Was ist in dieser Lösung nicht enthalten bzw. abgedeckt)

1 | Es wird nicht gewährleistet, dass das erstellte Model vollkommen identisch mit dem gescannten Objekt übereinstimmt. Es wird damit gerechnet, dass es geringfügige Abweichungen der Maße zwischen Ob- jekt und Modell gibt.

Tabelle 4: Abgrenzung (Was ist in dieser Lösung nicht enthalten bzw. abgedeckt)

## 4 Workflow

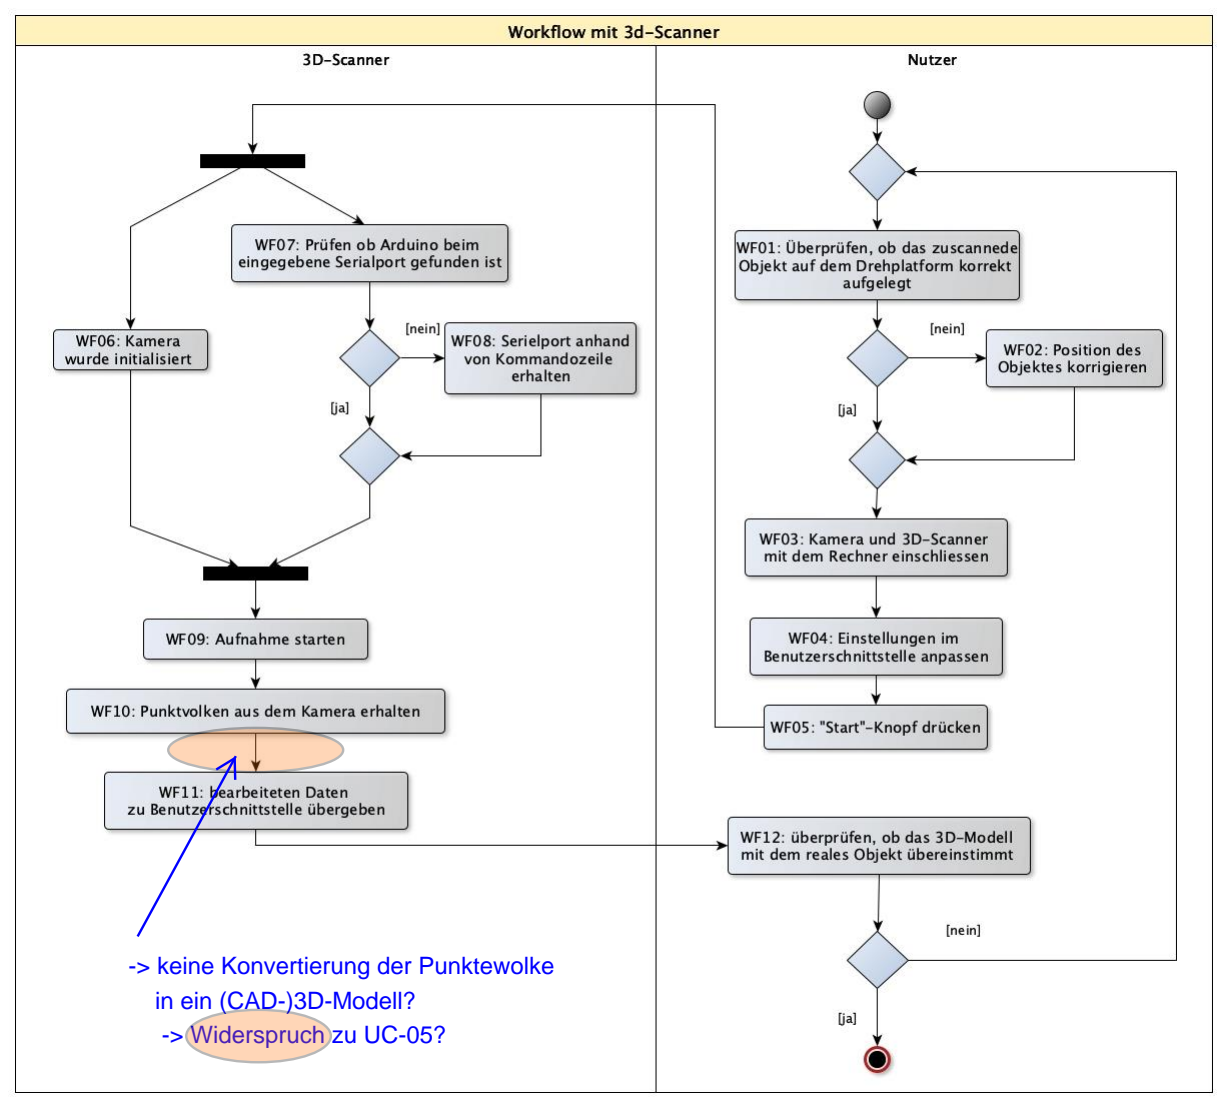
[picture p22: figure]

Abbildung 1: Workflow Diagramm 3D-Scanner und Nutzer

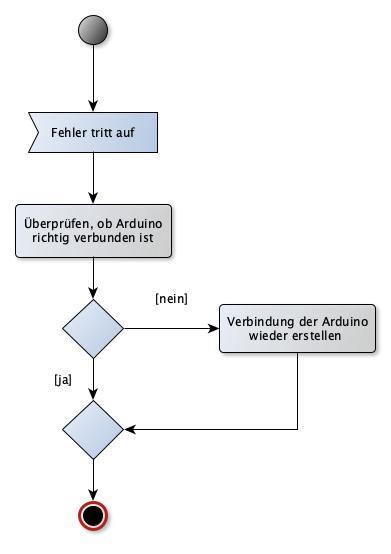
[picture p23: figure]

Abbildung 2: Workflow beim Fehlerauftreten

## 5 Funktionalität 5.1 Überblick

Die folgende Abbildung beschreibt das Use-Case Diagramm der Software.

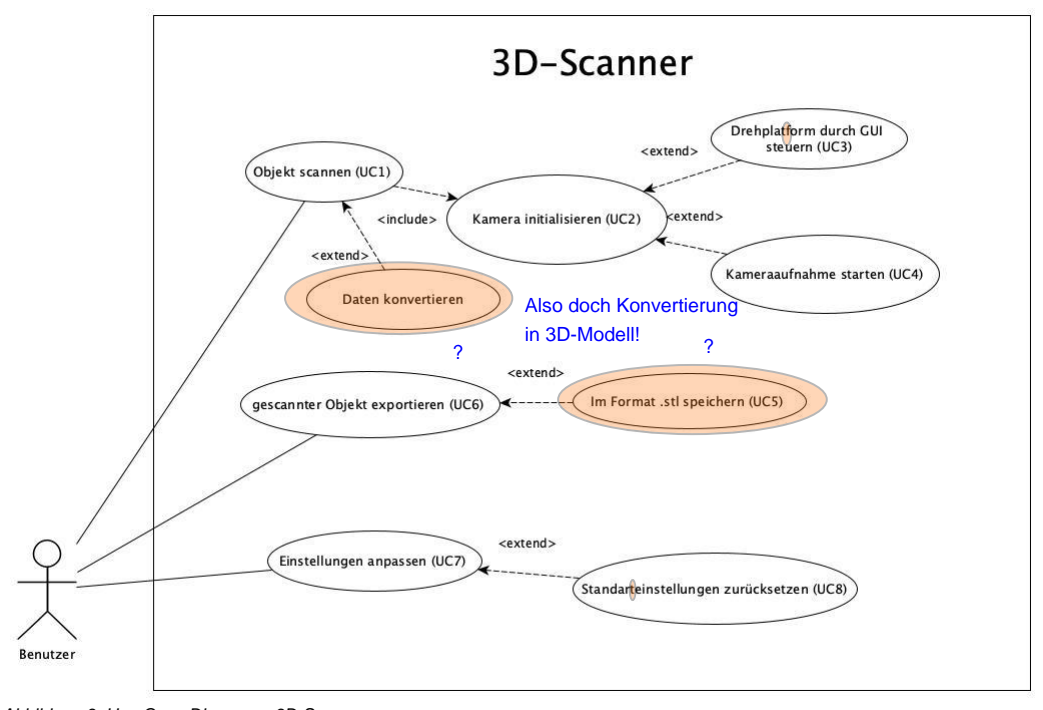
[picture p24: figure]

Abbildung 3: Use-Case Diagramm 3D-Scanner

Die folgende Abbildung beinhaltet die GUI der Software.

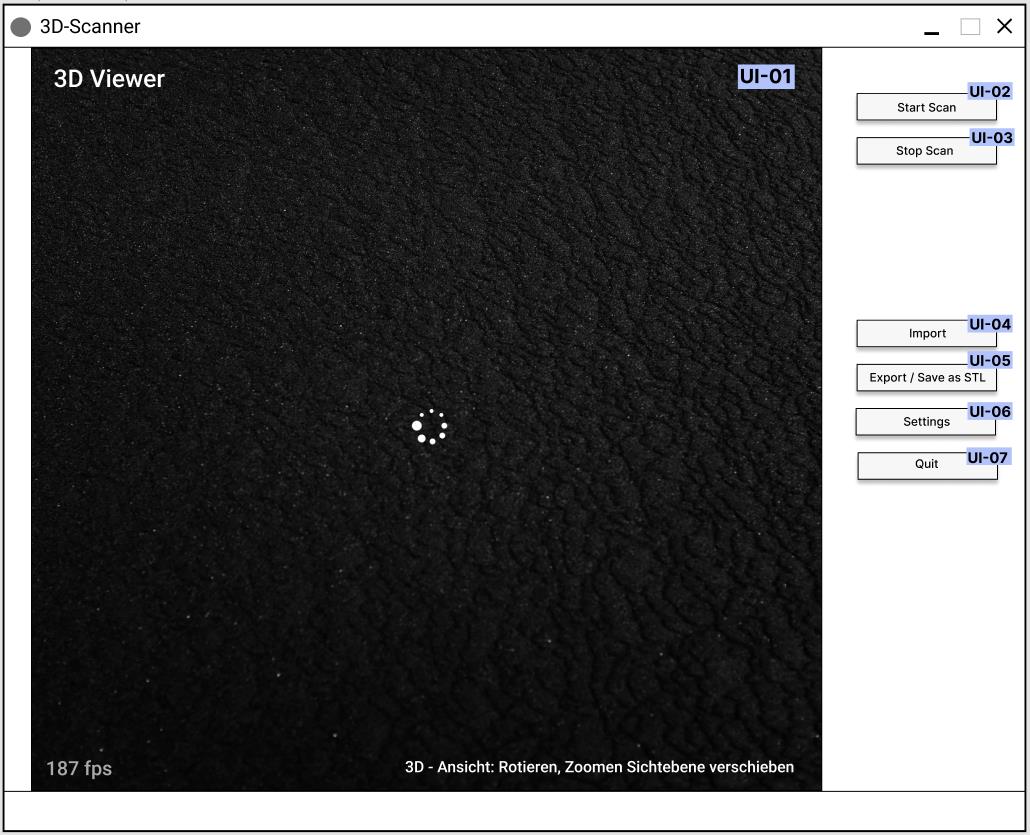
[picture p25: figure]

Abbildung 4: GUI Mockup mit UI Beschriftung

Die folgende Tabelle beschreibt die UI-Elemente unserer GUI.

UI-Element | UI-01 3D-Viewer | UI-02 Start Scan | UI-03 Stop Scan | UI-04 Import | UI-05 Export | UI-06 Settings | UI-07 Quit
Erklärung | Visuelle 3D An-zeige um das Objekt anzeigen zu lassen. In dem Viewer kann man das ge-scannte Objekt drehen, rotieren und zoomen. | Button der den Scan Prozess startet. | Button der den Scan Prozess stoppt. | Button der .stl Dateien zur Visuali-sierung öffnet | Button der gescann-ten Objek-te expor-tiert | Button um die Einstel-lungen zu öffnen. | Button zum Be-enden der Soft-ware

Tabelle 5: UI-Elemente mit Erklärungen


Abbildung 5: 3D-Sicht des Scanners

Abbildung 6: Draufsicht des Scanners


Abbildung 7: Seitenansicht des Scanners

Abbildung 8: Vorderansicht des Scanners

Objekt Scan

Die folgende Tabelle erläutert die Funktion “Objekt scannen”.

Zweck/Ziel | Mit dieser Funktion wird das Objekt welches sich auf der Plattform befindet, gescannt.
Akteur/Auslöser | User und System
Berechtigung | Keine spezifischen Rechte notwendig
WF-Rererenz | UC-01
Vorbedingung | • Benutzer hat das System erfolgreich mit allen Komponenten gestartet und befin- det sich in der GUI • Kamera ist angeschlossen und an der entsprechenden Position platziert • Objekt befindet sich auf der Plattform
Daten-Input | • Keine Daten notwendig
Verarbeitungs-schritte | 1. Funktion startet mittels eines Buttons auf der GUI 2. Gibt Information weiter, dass der User einen Scann gestartet hat 3. Empfängt die gewonnen Daten
Ergebnis | Das Objekt wurde gescannt, die aufgenommenen Daten sind bereit zur Weiterver-arbeitung (z.B. Export)
Plausibilitäten | Auflistung mögliche Plausibilitätsprüfungen, Attribut-Status**
Fehlerhandling | • In Der Benutzeroberfläche wird eine Fehlermeldung angezeigt • Aufforderung zum Überprüfen der Verbindungen von Kamera und Arduino
Folgeprozess | Verarbeitung der gewonnen Daten in die GUI
Out of Scope | Diese Funktion dient dazu den Scan zu starten und die gewonnen Daten weiterzu-leiten

Anforderung

Release

Test Cases
Tabelle 6: Funktionalität Objekt Scan

## 5.2 Kamera initialisieren

Die folgende Tabelle erläutert die Funktion “Initialisierung der Kamera”.

Zweck/Ziel | Durch diese Funktion werden die Nebenprozesse die für den Scan nötig sind gesteuert
Akteur/Auslöser | System
Berechtigung | Die Software benötigt administrative Rechte um auf die USB-Ports zugreifen zu können
WF-Rererenz | UC-02
Vorbedingung | • Kamera und Arduino sind angeschlossen • Software ist aktiv • Scan wurde durch User gestartet
Daten-Input | • Es sind keine Daten notwendig für diese Funktion • Funktion wird durch vorherige Funktion gestartet (UC-01)

Verarbeitungsschritte

1. Arduino wird Aufgefordert zum drehen der Plattform
2. Intel Realsense Kamera nimmt nötige Daten auf
3. Daten werden zur Weiterverarbeitung weitergeleitet
Ergebnis | Die Kamera und Plattform haben die nötigen Daten aufgenommen und sind bereit für den nächsten Scan
Plausibilitäten | Auflistung mögliche Plausibilitätsprüfungen, Attribut-Status**
Fehlerhandling | • In Der Benutzeroberfläche wird eine Fehlermeldung angezeigt • Aufforderung zum Überprüfen der Verbindungen von Kamera und Arduino
Folgeprozess | Die Funktion wird durch die Prozesse bei der Kamera und dem Arduino weitergeführt und endet damit die gewonnen Daten der Hauptfunktion UC-01 zurückzugeben
Out of Scope | Die Daten werden in dieser Funktion nicht verarbeitet, die Funktion dient lediglich zur Steuerung der nötigen Prozesse

Anforderung

Release

Test Cases | • Ansprechen der Kamera • Ansprechen des Arduinos

Tabelle 7: Funktionalität Kamera initialisieren

## 5.3 Drehplattform durch GUI steuern

Die folgende Tabelle erläutert die Funktion “Rotation der Plattform”.

Zweck/Ziel | Die Funktion ist dazu da die Plattform sich rotieren zu lassen
Akteur/Auslöser | System
Berechtigung | Keine Rechte notwendig
WF-Rererenz | UC-03
Vorbedingung | • Arduino ist am Computer angeschlossen
Daten-Input | • Es sind keine Daten notwendig
Verarbeitungs-schritte | 1. Stepper Motor dreht sich 2. Durch Stepper Motor dreht sich die Plattform
Ergebnis | Durch die Drehung (Rotation) der Plattform gelingt es der Kamera aus jeder Per-spektive zum Bild Daten aufzunehmen
Plausibilitäten | Auflistung mögliche Plausibilitätsprüfungen, Attribut-Status
Fehlerhandling | • In Der Benutzeroberfläche wird eine Fehlermeldung angezeigt • Aufforderung zum Überprüfen der Verbindungen von Kamera und Arduino
Folgeprozess | Während die Plattform rotiert werden Daten aufgenommen, diese Daten werden zur Weiterverarbeitung weitergeleitet durch UC-01
Out of Scope | Die Funktion dient nur zur Rotation der Kamera

Anforderung

Release

Test Cases | Rotation der Plattform außerhalb der Software
Tabelle 8: Funktionalität Drehplattform durch GUI steuern

## 5.4 Kameraaufnahme starten

Die folgende Tabelle erläutert die Funktion “Aufnahme durch die Kamera”.

Zweck/Ziel | In dieser Funktion werden die Daten durch die Kamera aufgenommen
Akteur/Auslöser | System
Berechtigung | Es sind keine Rechte notwendig
WF-Rererenz | UC-04
Vorbedingung | • | Kamera ist angeschlossen
Daten-Input | • | Es sind keine Daten notwendig
Verarbeitungs-schritte | 1. Kamera schaltet in den Tiefenbilder Modus 2. Kamera schießt Bilder in bestimmten Zeitabständen
Ergebnis | Durch die geschossenen Bilder ist ein Datensatz entstanden

Plausibilitäten

Fehlerhandling | • In Der Benutzeroberfläche wird eine Fehlermeldung angezeigt
| • Aufforderung zum Überprüfen der Verbindungen von Kamera und Arduino
Folgeprozess | Der aufgenommene Datensatz wird weitergeleitet an UC-01
Out of Scope | Diese Funktion ist lediglich dazu verantwortet die Bilder aufzunehmen

Anforderung

Release

Test Cases | Die Kamera wird vorher auf Funktionalität getestet
Tabelle 9: Funktionalität Kameraaufnahme starten

## 5.5 Konvertierung der Daten

Die folgende Tabelle erläutert die Funktion “Konvertierung der Daten”.

Zweck/Ziel | In dieser Funktion werden die Daten Verarbeitet
Akteur/Auslöser | System
Berechtigung | Es sind keine Rechte notwendig
WF-Rererenz | UC-09
Vorbedingung | • Die Plattform hat eine 360° Drehung hinter sich • Die Kamera hat Tiefenbilder geschossen • Der Datensatz ist vollständig gefüllt
Daten-Input | • Mehrere Tiefenbilder vom Objekt

Verarbeitungsschritte

1. Datensatz wird verarbeitet
2. Objekt wird in der GUI visualisiert
Ergebnis | Das Objekt ist digitalisiert und wird visuell in der GUI angezeigt

Plausibilitäten

Fehlerhandling | • In Der Benutzeroberfläche wird eine Fehlermeldung angezeigt • Aufforderung zum Wiederholen des Scans • Gegebenenfalls genaue Beschreibung des Fehlers
Folgeprozess | Der Object Scan ist somit beendet, der Nutzer kann nun die nächsten Prozesse durch die GUI einleiten
Out of Scope | Diese Funktion nimmt ist nicht für die Aufnahme der Daten verantwortlich, sie kriegt die Daten und verarbeitet sie

Anforderung

Release

Test Cases

Tabelle 10: Funktionalität Konvertierung der Daten


Abbildung 9: GUI Mockup – Nach Kameraaufnahme + Konvertierung der Daten

## 5.6 Gescanntes Objekt Exportieren

Die folgende Tabelle erläutert die Funktion “Exportierung des gescannten Objekts”.

Zweck/Ziel | In dieser Funktion kann der User das gescannte Objekt exportieren um es für jegliches zu Benutzen
Akteur/Auslöser | User, System
Berechtigung | Es sind Festplatten Rechte nötig um die Datei abzuspeichern
WF-Rererenz | UC-06
Vorbedingung | • Erfolgreicher Scan ohne Fehler • Gescanntes Objekt ist in GUI visualisiert
Daten-Input | • Output vom Objekt Scan (UC-01) wird hier weiterverwendet
Verarbeitungs-schritte | 1. Daten werden in eine Datei konvertiert 2. User wählt Ort aus um die Datei abzuspeichern 3. Datei wird abgespeichert
Ergebnis | Das gescannte Objekt ist in verschiedene andere Software weiterverwendbar

Plausibilitäten

Fehlerhandling | • In Der Benutzeroberfläche wird eine Fehlermeldung angezeigt • Aufforderung zur Überprüfung des Speichers
Folgeprozess | Der User hat erfolgreich die Hauptfunktion der Software beendet, und könnte nun mit einem neuen Objekt fortfahren

Out of Scope

Anforderung

Release

Test Cases | Es werden mehrere vorgegebene Objekte abgespeichert
Tabelle 11: Funktionalität Gescanntes Objekt exportieren

## 5.7 Im Format .stl speichern

Die folgende Tabelle erläutert die Funktion “Konvertierung der Daten in das .stl Dateiformat”.

Zweck/Ziel | In dieser Funktion wird die zu abspeichernde Datei in eine .stl Datei konvertiert
Akteur/Auslöser | System
Berechtigung | Es sind keine Rechte notwendig
WF-Rererenz | UC-05
Vorbedingung | • | Es besteht eine Datei
Daten-Input | • Output vom Objekt Scan (UC-01) wird hier weiterverwendet
Verarbeitungs-schritte | 1. Datei wird in .stl konvertiert
Ergebnis | Es besteht eine .stl Datei, die das gescannte Objekt beinhaltet

Plausibilitäten

Fehlerhandling | • In Der Benutzeroberfläche wird eine Fehlermeldung angezeigt • Aufforderung zur Überprüfung des Speichers
Folgeprozess | Der User hat erfolgreich die Hauptfunktion der Software beendet, und könnte nun mit einem neuen Objekt fortfahren

Out of Scope

Anforderung

Release

Test Cases | Die Kamera wird vorher auf Funktionalität getestet
Tabelle 12: Im Format .stl speichern


Abbildung 10: GUI Mockup – Export Button Ansicht

## 5.8 Einstellungen anpassen

Die folgende Tabelle erläutert die Funktion “Einstellungen”.

Zweck/Ziel | In dieser Funktionen können interne Einstellungen angepasst werden
Akteur/Auslöser | User, System
Berechtigung | Es sind keine Rechte notwendig
WF-Rererenz | UC-07
Vorbedingung | • Die Einstellungen sind nur über die GUI erreichbar
Daten-Input | • Es sind keine Daten notwendig

Verarbeitungsschritte

1. GUI schaltet in Einstellungsfenster
2. Verschiede Dinge können angepasst werden(z.B Port für Arduino)
Ergebnis | Software benutzt nun richtigen Port für Arduino
Plausibilitäten | Darkmode
Fehlerhandling | • In Der Benutzeroberfläche wird eine Fehlermeldung angezeigt
| • Aufforderung zum Starten der Software mit Admin Rechten
Folgeprozess | Der User kann neuen Scan starten
Out of Scope | Durch die Einstellungen kann man nicht erhebliche Änderungen an der Software ausführen, wie Anpassung der Toleranzen, etc.

Anforderung

Release

Test Cases
Tabelle 13: Funktionalität Einstellung anpassen


Abbildung 11: GUI Mockup – Einstellung Button Ansicht

## 5.9 Standarteinstellungen zurücksetzen

Die folgende Tabelle erläutert die Funktion “Standarteinstellungen zurücksetzen”.

Zweck/Ziel | In dieser Funktionen werden die Einstellungen auf Werkseinstellungen zurückgesetzt
Akteur/Auslöser | User, System
Berechtigung | Es sind keine Rechte notwendig
WF-Rererenz | UC-08
Vorbedingung | • | Die Einstellungen sind nur über die GUI erreichbar
Daten-Input | • | Die Werkseinstellungen sind innerhalb der Software gespeichert

Verarbeitungsschritte

1. Die Werkseinstellungen werden übernommen
2. Die aktuellen Einstellungen werde mit den Werkseinstellungen überschrie-
| | ben
Ergebnis | Die Software ist auf dem Stand wie sie runtergeladen wurde

Plausibilitäten

Fehlerhandling | • In Der Benutzeroberfläche wird eine Fehlermeldung angezeigt • Aufforderung zum Starten der Software mit Admin Rechten
Folgeprozess | Der User kann neuen Scan starten

Out of Scope

Anforderung

Release

Test Cases
Tabelle 14: Standardeinstellung zurücksetzen

## Modulabhängigkeiten

Modul | Beschreibung
Programmierung | Die Software wird programmiert
Konstruktion | Es wird eine Plattform konstruiert um das Objekt draufzustellen
Mechatronik | Es wird ein Mikroprozessor zur Steuerung des Stepper Motors verwendet

Tabelle 15: Modulabhängigkeiten

## 6 Wer hat was gemacht

Autor | Aufgabe/Kapitel | Anteil
Vinh Thong Trinh | Alles | 25%
Habib Ben-Khedher | Alles | 25%
Mert Karadeniz | Alles | 25%
William Eppel | Alles | 25%
Tabelle 16: Wer hat was gemacht

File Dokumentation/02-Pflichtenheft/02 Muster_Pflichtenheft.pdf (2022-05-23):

### Pflichtenheft

3D-Scanner mit einer Intel RealSense

© HTW Berlin

# Pflichtenheft

## HTW Berlin 3D-Scanner mit einer Intel RealSense

Autor: | Vinh Thong Trinh, Mert Karadeniz, Habib Ben Khedher, William Eppel
Letzte Änderung: 24. Mai 2022
Dateiname: | 02 Muster_Pflichtenheft.docx
Version: | 1.0

Copyright

© Mohammad Abuosba

Die Weitergabe, Vervielfältigung oder anderweitige Nutzung dieses Dokumentes oder Teile davon ist unabhängig vom Zweck oder in welcher Form untersagt, es sei denn, die Rechteinhaber/In hat ihre ausdrückliche schriftliche Genehmigung erteilt.

© HTW Berlin

Version Historie

Version | Datum | Verantwortlich | Änderung
0.1 | 05.05.2022 | Vinh Thong Trinh, Mert Karadeniz, Habib Ben Khedher, William Eppel | Einleitung, Überblick
0.2 | 18.05.2022 | Vinh Thong Trinh, Mert Karadeniz, Habib Ben Khedher, William Eppel | Funktionalitäten, Use-Case, Workflow
0.3 | 23.05.2022 | Vinh Thong Trinh, Mert
Karadeniz, | Habib | Ben
Khedher, William Eppel

Optimiert, überarbeitet, Rechtschreibung und Grammatik

1.0 | 25.05.2022 | Vinh Thong Trinh, Mert
Karadeniz, | Habib | Ben
Khedher, William Eppel

Abgabe

I

## Inhaltsverzeichnis

Abbildungsverzeichnis | II
Tabellenverzeichnis | III
Verzeichnis vorhandener Dokumente | IV

II

## Abbildungsverzeichnis

III

## Tabellenverzeichnis

Tabelle 1: Verzeichnis vorhandener Dokumente | IV

IV

## Verzeichnis vorhandener Dokumente

Alle für die vorliegende Spezifikation ergänzenden Unterlagen müssen hier aufgeführt werden.

Dokument | Autor | Datum
Lastenheft | HTW-Berlin | 26.04.2022
Tabelle 1: Verzeichnis vorhandener Dokumente

© HTW Berlin | Seite

## 1 Überblick

Im Projekt soll ein 3D-Scanner entwickelt werden, der diverse Objekte, die bestimmte Voraussetzungen erfüllen, digitalisieren kann, sodass die erstellten digitalen Kopien weiterverwendet werden können. Die Schwierigkeit besteht darin, ein Produkt zu schaffen, das einen niedrigen Einkaufspreis sowie niedrige Instandhaltungskosten aufweist und zudem Kompakt und leicht zu transportieren ist. Die Schnittstelle der Hardware und Software besteht aus einem Arduino Mikroprozessor. Die Daten, die mithilfe der Software zur Digitalisierung des Objektes führen, werden durch die Intel Realsense Kamera Model D415 aufgenommen. Die aufgenommenen Daten liegen in Form von Tiefenbildern vor.

Das Produkt soll aus 3D - gedruckten Einzelteilen (Material) bestehen, um ein bestimmtes Gewicht nicht zu überschreiten. Durch intelligente Konzipierung der Konstruktion, soll geboten werden, dass der Nutzer allein die Instandhaltung gewährleisten kann. Der niedrige Einkaufspreis zeichnet sich durch die Nutzung einer einzigen Kamera aus.

## 2 Hauptziele

In der folgenden Tabelle sind die Hauptziele des Projektes mit den jeweiligen Implementationen aufgeführt.

# | Ziel | Beschreibung der Implementation

1 | Erkennung eines Objektes | Intel Realsense D415(Tiefenkamera) Python Package PyRealSense2
2 | Anzeigen des 3D-Objektes | Python Package Open3D und PIL
3 | Ansteuerung der Hardware | Python Package PySerial
5 | Ansteuerung Schrittmotor | Arduino Uno
6 | Export des 3D-Objektes (.stl) | Python Package Open3D

Tabelle 2: Hauptziele mit Beschreibung

## 3 Annahmen und Abgrenzungen

In der folgenden Tabelle sind unsere Annahmen nummeriert beschrieben worden.

# | Annahmen

1 | Besitz eines Rechners mit USB-Anschluss
2 | Die Software ist auf dem Rechner installiert
3 | Bilderkennung über Intel Realsense
4 | Objekt darf keine spiegelnde Oberfläche besitzen
5 | Objekt ist max. groß wie eine Tasse, 8cm Durchmesser, 8,5cm Höhe
6 | Das Gewicht des Objektes überschreitet nicht 350 Gramm

Tabelle 3: fachliche und technische Annahmen

In der folgenden Tabelle sind unsere Abgrenzungen nummeriert beschrieben worden.

# | Abgrenzungen (Was ist in dieser Lösung nicht enthalten bzw. abgedeckt)

1 | Es wird nicht gewährleistet, dass das erstellte Model vollkommen identisch mit dem gescannten Objekt übereinstimmt. Es wird damit gerechnet, dass es geringfügige Abweichungen der Maße zwischen Ob- jekt und Modell gibt.

Tabelle 4: Abgrenzung (Was ist in dieser Lösung nicht enthalten bzw. abgedeckt)

## 4 Workflow


Abbildung 1: Workflow Diagramm 3D-Scanner und Nutzer


Abbildung 2: Workflow beim Fehlerauftreten

## 5 Funktionalität 5.1 Überblick

Die folgende Abbildung beschreibt das Use-Case Diagramm der Software.


Abbildung 3: Use-Case Diagramm 3D-Scanner

Die folgende Abbildung beinhaltet die GUI der Software.


Abbildung 4: GUI Mockup mit UI Beschriftung

Die folgende Tabelle beschreibt die UI-Elemente unserer GUI.

UI-Element | UI-01 3D-Viewer | UI-02 Start Scan | UI-03 Stop Scan | UI-04 Import | UI-05 Export | UI-06 Settings | UI-07 Quit
Erklärung | Visuelle 3D An-zeige um das Objekt anzeigen zu lassen. In dem Viewer kann man das ge-scannte Objekt drehen, rotieren und zoomen. | Button der den Scan Prozess startet. | Button der den Scan Prozess stoppt. | Button der .stl Dateien zur Visuali-sierung öffnet | Button der gescann-ten Objek-te expor-tiert | Button um die Einstel-lungen zu öffnen. | Button zum Be-enden der Soft-ware

Tabelle 5: UI-Elemente mit Erklärungen


Abbildung 5: 3D-Sicht des Scanners

Abbildung 6: Draufsicht des Scanners


Abbildung 7: Seitenansicht des Scanners

Abbildung 8: Vorderansicht des Scanners

Objekt Scan

Die folgende Tabelle erläutert die Funktion “Objekt scannen”.

Zweck/Ziel | Mit dieser Funktion wird das Objekt welches sich auf der Plattform befindet, gescannt.
Akteur/Auslöser | User und System
Berechtigung | Keine spezifischen Rechte notwendig
WF-Rererenz | UC-01
Vorbedingung | • Benutzer hat das System erfolgreich mit allen Komponenten gestartet und befin- det sich in der GUI • Kamera ist angeschlossen und an der entsprechenden Position platziert • Objekt befindet sich auf der Plattform
Daten-Input | • Keine Daten notwendig
Verarbeitungs-schritte | 1. Funktion startet mittels eines Buttons auf der GUI 2. Gibt Information weiter, dass der User einen Scann gestartet hat 3. Empfängt die gewonnen Daten
Ergebnis | Das Objekt wurde gescannt, die aufgenommenen Daten sind bereit zur Weiterver-arbeitung (z.B. Export)
Plausibilitäten | Auflistung mögliche Plausibilitätsprüfungen, Attribut-Status**
Fehlerhandling | • In Der Benutzeroberfläche wird eine Fehlermeldung angezeigt • Aufforderung zum Überprüfen der Verbindungen von Kamera und Arduino
Folgeprozess | Verarbeitung der gewonnen Daten in die GUI
Out of Scope | Diese Funktion dient dazu den Scan zu starten und die gewonnen Daten weiterzu-leiten

Anforderung

Release

Test Cases
Tabelle 6: Funktionalität Objekt Scan

## 5.2 Kamera initialisieren

Die folgende Tabelle erläutert die Funktion “Initialisierung der Kamera”.

Zweck/Ziel | Durch diese Funktion werden die Nebenprozesse die für den Scan nötig sind gesteuert
Akteur/Auslöser | System
Berechtigung | Die Software benötigt administrative Rechte um auf die USB-Ports zugreifen zu können
WF-Rererenz | UC-02
Vorbedingung | • Kamera und Arduino sind angeschlossen • Software ist aktiv • Scan wurde durch User gestartet
Daten-Input | • Es sind keine Daten notwendig für diese Funktion • Funktion wird durch vorherige Funktion gestartet (UC-01)

Verarbeitungsschritte

1. Arduino wird Aufgefordert zum drehen der Plattform
2. Intel Realsense Kamera nimmt nötige Daten auf
3. Daten werden zur Weiterverarbeitung weitergeleitet
Ergebnis | Die Kamera und Plattform haben die nötigen Daten aufgenommen und sind bereit für den nächsten Scan
Plausibilitäten | Auflistung mögliche Plausibilitätsprüfungen, Attribut-Status**
Fehlerhandling | • In Der Benutzeroberfläche wird eine Fehlermeldung angezeigt • Aufforderung zum Überprüfen der Verbindungen von Kamera und Arduino
Folgeprozess | Die Funktion wird durch die Prozesse bei der Kamera und dem Arduino weitergeführt und endet damit die gewonnen Daten der Hauptfunktion UC-01 zurückzugeben
Out of Scope | Die Daten werden in dieser Funktion nicht verarbeitet, die Funktion dient lediglich zur Steuerung der nötigen Prozesse

Anforderung

Release

Test Cases | • Ansprechen der Kamera • Ansprechen des Arduinos

Tabelle 7: Funktionalität Kamera initialisieren

## 5.3 Drehplattform durch GUI steuern

Die folgende Tabelle erläutert die Funktion “Rotation der Plattform”.

Zweck/Ziel | Die Funktion ist dazu da die Plattform sich rotieren zu lassen
Akteur/Auslöser | System
Berechtigung | Keine Rechte notwendig
WF-Rererenz | UC-03
Vorbedingung | • Arduino ist am Computer angeschlossen
Daten-Input | • Es sind keine Daten notwendig
Verarbeitungs-schritte | 1. Stepper Motor dreht sich 2. Durch Stepper Motor dreht sich die Plattform
Ergebnis | Durch die Drehung (Rotation) der Plattform gelingt es der Kamera aus jeder Per-spektive zum Bild Daten aufzunehmen
Plausibilitäten | Auflistung mögliche Plausibilitätsprüfungen, Attribut-Status
Fehlerhandling | • In Der Benutzeroberfläche wird eine Fehlermeldung angezeigt • Aufforderung zum Überprüfen der Verbindungen von Kamera und Arduino
Folgeprozess | Während die Plattform rotiert werden Daten aufgenommen, diese Daten werden zur Weiterverarbeitung weitergeleitet durch UC-01
Out of Scope | Die Funktion dient nur zur Rotation der Kamera

Anforderung

Release

Test Cases | Rotation der Plattform außerhalb der Software
Tabelle 8: Funktionalität Drehplattform durch GUI steuern

## 5.4 Kameraaufnahme starten

Die folgende Tabelle erläutert die Funktion “Aufnahme durch die Kamera”.

Zweck/Ziel | In dieser Funktion werden die Daten durch die Kamera aufgenommen
Akteur/Auslöser | System
Berechtigung | Es sind keine Rechte notwendig
WF-Rererenz | UC-04
Vorbedingung | • | Kamera ist angeschlossen
Daten-Input | • | Es sind keine Daten notwendig
Verarbeitungs-schritte | 1. Kamera schaltet in den Tiefenbilder Modus 2. Kamera schießt Bilder in bestimmten Zeitabständen
Ergebnis | Durch die geschossenen Bilder ist ein Datensatz entstanden

Plausibilitäten

Fehlerhandling | • In Der Benutzeroberfläche wird eine Fehlermeldung angezeigt
| • Aufforderung zum Überprüfen der Verbindungen von Kamera und Arduino
Folgeprozess | Der aufgenommene Datensatz wird weitergeleitet an UC-01
Out of Scope | Diese Funktion ist lediglich dazu verantwortet die Bilder aufzunehmen

Anforderung

Release

Test Cases | Die Kamera wird vorher auf Funktionalität getestet
Tabelle 9: Funktionalität Kameraaufnahme starten

## 5.5 Konvertierung der Daten

Die folgende Tabelle erläutert die Funktion “Konvertierung der Daten”.

Zweck/Ziel | In dieser Funktion werden die Daten Verarbeitet
Akteur/Auslöser | System
Berechtigung | Es sind keine Rechte notwendig
WF-Rererenz | UC-09
Vorbedingung | • Die Plattform hat eine 360° Drehung hinter sich • Die Kamera hat Tiefenbilder geschossen • Der Datensatz ist vollständig gefüllt
Daten-Input | • Mehrere Tiefenbilder vom Objekt

Verarbeitungsschritte

1. Datensatz wird verarbeitet
2. Objekt wird in der GUI visualisiert
Ergebnis | Das Objekt ist digitalisiert und wird visuell in der GUI angezeigt

Plausibilitäten

Fehlerhandling | • In Der Benutzeroberfläche wird eine Fehlermeldung angezeigt • Aufforderung zum Wiederholen des Scans • Gegebenenfalls genaue Beschreibung des Fehlers
Folgeprozess | Der Object Scan ist somit beendet, der Nutzer kann nun die nächsten Prozesse durch die GUI einleiten
Out of Scope | Diese Funktion nimmt ist nicht für die Aufnahme der Daten verantwortlich, sie kriegt die Daten und verarbeitet sie

Anforderung

Release

Test Cases

Tabelle 10: Funktionalität Konvertierung der Daten


Abbildung 9: GUI Mockup – Nach Kameraaufnahme + Konvertierung der Daten

## 5.6 Gescanntes Objekt Exportieren

Die folgende Tabelle erläutert die Funktion “Exportierung des gescannten Objekts”.

Zweck/Ziel | In dieser Funktion kann der User das gescannte Objekt exportieren um es für jegliches zu Benutzen
Akteur/Auslöser | User, System
Berechtigung | Es sind Festplatten Rechte nötig um die Datei abzuspeichern
WF-Rererenz | UC-06
Vorbedingung | • Erfolgreicher Scan ohne Fehler • Gescanntes Objekt ist in GUI visualisiert
Daten-Input | • Output vom Objekt Scan (UC-01) wird hier weiterverwendet
Verarbeitungs-schritte | 1. Daten werden in eine Datei konvertiert 2. User wählt Ort aus um die Datei abzuspeichern 3. Datei wird abgespeichert
Ergebnis | Das gescannte Objekt ist in verschiedene andere Software weiterverwendbar

Plausibilitäten

Fehlerhandling | • In Der Benutzeroberfläche wird eine Fehlermeldung angezeigt • Aufforderung zur Überprüfung des Speichers
Folgeprozess | Der User hat erfolgreich die Hauptfunktion der Software beendet, und könnte nun mit einem neuen Objekt fortfahren

Out of Scope

Anforderung

Release

Test Cases | Es werden mehrere vorgegebene Objekte abgespeichert
Tabelle 11: Funktionalität Gescanntes Objekt exportieren

## 5.7 Im Format .stl speichern

Die folgende Tabelle erläutert die Funktion “Konvertierung der Daten in das .stl Dateiformat”.

Zweck/Ziel | In dieser Funktion wird die zu abspeichernde Datei in eine .stl Datei konvertiert
Akteur/Auslöser | System
Berechtigung | Es sind keine Rechte notwendig
WF-Rererenz | UC-05
Vorbedingung | • | Es besteht eine Datei
Daten-Input | • Output vom Objekt Scan (UC-01) wird hier weiterverwendet
Verarbeitungs-schritte | 1. Datei wird in .stl konvertiert
Ergebnis | Es besteht eine .stl Datei, die das gescannte Objekt beinhaltet

Plausibilitäten

Fehlerhandling | • In Der Benutzeroberfläche wird eine Fehlermeldung angezeigt • Aufforderung zur Überprüfung des Speichers
Folgeprozess | Der User hat erfolgreich die Hauptfunktion der Software beendet, und könnte nun mit einem neuen Objekt fortfahren

Out of Scope

Anforderung

Release

Test Cases | Die Kamera wird vorher auf Funktionalität getestet
Tabelle 12: Im Format .stl speichern


Abbildung 10: GUI Mockup – Export Button Ansicht

## 5.8 Einstellungen anpassen

Die folgende Tabelle erläutert die Funktion “Einstellungen”.

Zweck/Ziel | In dieser Funktionen können interne Einstellungen angepasst werden
Akteur/Auslöser | User, System
Berechtigung | Es sind keine Rechte notwendig
WF-Rererenz | UC-07
Vorbedingung | • Die Einstellungen sind nur über die GUI erreichbar
Daten-Input | • Es sind keine Daten notwendig

Verarbeitungsschritte

1. GUI schaltet in Einstellungsfenster
2. Verschiede Dinge können angepasst werden(z.B Port für Arduino)
Ergebnis | Software benutzt nun richtigen Port für Arduino
Plausibilitäten | Darkmode
Fehlerhandling | • In Der Benutzeroberfläche wird eine Fehlermeldung angezeigt
| • Aufforderung zum Starten der Software mit Admin Rechten
Folgeprozess | Der User kann neuen Scan starten
Out of Scope | Durch die Einstellungen kann man nicht erhebliche Änderungen an der Software ausführen, wie Anpassung der Toleranzen, etc.

Anforderung

Release

Test Cases
Tabelle 13: Funktionalität Einstellung anpassen


Abbildung 11: GUI Mockup – Einstellung Button Ansicht

## 5.9 Standarteinstellungen zurücksetzen

Die folgende Tabelle erläutert die Funktion “Standarteinstellungen zurücksetzen”.

Zweck/Ziel | In dieser Funktionen werden die Einstellungen auf Werkseinstellungen zurückgesetzt
Akteur/Auslöser | User, System
Berechtigung | Es sind keine Rechte notwendig
WF-Rererenz | UC-08
Vorbedingung | • | Die Einstellungen sind nur über die GUI erreichbar
Daten-Input | • | Die Werkseinstellungen sind innerhalb der Software gespeichert

Verarbeitungsschritte

1. Die Werkseinstellungen werden übernommen
2. Die aktuellen Einstellungen werde mit den Werkseinstellungen überschrie-
| | ben
Ergebnis | Die Software ist auf dem Stand wie sie runtergeladen wurde

Plausibilitäten

Fehlerhandling | • In Der Benutzeroberfläche wird eine Fehlermeldung angezeigt • Aufforderung zum Starten der Software mit Admin Rechten
Folgeprozess | Der User kann neuen Scan starten

Out of Scope

Anforderung

Release

Test Cases
Tabelle 14: Standardeinstellung zurücksetzen

## Modulabhängigkeiten

Modul | Beschreibung
Programmierung | Die Software wird programmiert
Konstruktion | Es wird eine Plattform konstruiert um das Objekt draufzustellen
Mechatronik | Es wird ein Mikroprozessor zur Steuerung des Stepper Motors verwendet

Tabelle 15: Modulabhängigkeiten

## 6 Wer hat was gemacht

Autor | Aufgabe/Kapitel | Anteil
Vinh Thong Trinh | Alles | 25%
Habib Ben-Khedher | Alles | 25%
Mert Karadeniz | Alles | 25%
William Eppel | Alles | 25%
Tabelle 16: Wer hat was gemacht

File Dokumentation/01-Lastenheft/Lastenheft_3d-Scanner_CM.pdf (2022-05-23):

### Lastenheft 3D-Scanner

© HTW Berlin

# Lastenheft

## HTW Berlin 3D-Scanner mit einer Intel RealSense

Autor: | Vinh Thong Trinh, Mert Karadeniz, Habib Ben Khedher, William Eppel
Letzte Änderung: 26. April 2022
Dateiname: | Lastenheft
Version: | 0.2

Copyright

© Mohammad Abuosba

Die Weitergabe, Vervielfältigung oder anderweitige Nutzung dieses Dokumentes oder Teile davon ist unabhängig vom Zweck oder in welcher Form untersagt, es sei denn, die Rechteinhaber/In hat ihre ausdrückliche schriftliche Genehmigung erteilt.

© HTW Berlin

Version Historie:

Version: | Datum: | Verantwortlich | Änderung
0.1 | 12.04.2022 | Alle | Initiale Dokumenterstellung - Lastenheft
0.2 | 18.04.2022 | Alle | Erweiterungen
0.3 | 19.04.2022 | Alle | Endgültiger Entwurf
1.0 | 24.04.2022 | Alle | Finalisierung

© HTW Berlin | Seite 1

## I Inhaltsverzeichnis

II Abbildungsverzeichnis | Fehler! Textmarke nicht definiert.

## II Abbildungsverzeichnis

## 1 Einleitung

Digitalisierung ist ein großer Begriff unter dem man grundlegend die Erfassung von Informationen physischer Objekte in Formate versteht, welche sich zur Verarbeitung oder Speicherung in digitaltechnischen Systemen eignen. Durch Digitalisierung des Objektes vergrößert sich das Spektrum an Möglichkeiten mit dem Objekt um ein Vielfaches.

3D-Scanner sind oft stationär und besitzen mehrere Kameras die auf einen Punkt gerichtet sind. Die Kameras sind keine herkömmlichen Kameras, die Farbinformationen sammeln, sondern Kameras die durch Tiefenbilder Informationen über den Abstand zur Oberfläche des Objekts aufnehmen können. Durch die ermittelten Informationen wird das gescannte Objekt digital rekonstruiert.

## 2 Ausgangsituation

Derzeit werden zum Digitalisieren der Objekte 3D-Scanner genutzt. Die Kosten der Geräte sind für Personen mit durchschnittlichem Einkommen nicht einfach bezahlbar. Außerdem sind die meisten 3D-Scanner sehr groß und immobil. Zudem ist hinzuzufügen, dass die Scanner keine Wartbereitschaft besitzen und ausschließlich vom Hersteller repariert werden können.

Unser Team sollte eine Lösung finden um die Kosten eines derartigen Scanners zu minimieren. Zudem sind die Eigenschaften des Projektes aus Mobilität und Kompaktheit auszuzeichnen. Durch die Kompaktheit, sollte die Technik soweit einsichtig werden, dass Nutzer bei Problemen selber Tatkräftig werden können.

## 3 Zielsetzung

Ziel des Projektes ist es ein Produkt zu schaffen mit dem jeder Interessierte die Option hat diverse Objekte zu digitalisieren. Es soll die Möglichkeit geboten werden die Objekte zu scannen und daraus 3D – Modelle zu erstellen, die anschließend gedruckt werden können.

Das zu scannende Objekt soll auf eine rotierende Plattform platziert werden können. Durch nur eine Kamera soll das Objekt anschließend erfasst werden. Das System soll durch die erfassten Daten ein 3D-Modell erstellen, welches in einem bestimmten Dateityp – Format gespeichert werden soll. Die gespeicherten Daten können anschließend weiterverarbeitet werden um das Objekt beispielsweise zu drucken.

Die Bedienung des Systems soll einfach und intuitiv sein, sodass Nutzer ohne spezifisches Fachwissen dieses benutzen können.

Der Kostenpunkt des Produkts sollte weitestgehend minimiert werden um das Produkt für jeden interessierten erwerbbar zu machen.

## 4 Anforderungen

## 4.1 Software

### 4.1.1 Funktionale Anforderungen

Nr. | Gruppe | Beschreibung | Priorität
FA-1 | Objekt-Plattform
FA-1.1 | Plattform zum Stand und Fixierung des Objekts | hoch
FA-1.2 | Verbindung zur Kamera durch ein Standfuß | wenig
FA-1.3 | Kamerahalterung | mittel
FA-2 | Kamera
FA-2.1 | | Es soll eine einzige Kamera zum Scan benutzt werden | hoch
FA-2.2 | Kamera asynchron einbinden | mittel
FA-2.3 | Kamera sollte automatisch ausgewählt werden bei Ver- bindung des Kabels | hoch
FA-3 | GUI
FA-3.1 | Desktop Anwendung | hoch
FA-3.2 | Einfache Benutzeroberfläche | hoch
FA-3.3 | Übersichtlich und einfache Steuerung | hoch
FA-3.4 | Scan eines Objektes soll durch einen Druck auf einen Button möglich sein | hoch
FA-3.5 | Gescanntes Objekt visualisieren | mittel
FA-3.6 | | Gescanntes Objekt exportieren | hoch
FA-3.7 | | Exportierte Objekte wieder importieren können zum visu-alisieren | mittel
FA-4 | Output
FA-4.1 | | Gescanntes Objekt soll gedruckt werden können | mittel
FA-4.2 | Dateityp: z.B. STL, OBJ, … | hoch

### 4.1.2 Nicht-funktionale Anforderungen

Nr. | Gruppe | Beschreibung | Priorität
NFA 1 | Zuverlässigkeit
NFA-1.1 | | Das System ist sicher und geschützt. | hoch
NFA-1.2 | | Die Hardware muss vor physischen Schäden geschützt werden. | hoch
NFA 2 | Benutzbarkeit
NFA-2.1 | | Das System lässt sich vom Benutzer ohne Handbuch be-dienen. | hoch
NFA-2.2 | | GUI ist einfach zu bedienen. | mittel
NFA 3 | Effizienz
NFA-3.1 | | Der Scan sollte nicht länger als 1 Minuten andauern. | hoch
| | Die Drehplattform soll sich ohne Probleme drehen kön-nen. | hoch
NFA 4 | Wartung
NFA-4.1 | | Quellcode soll gut formatiert und kommentiert sein. | hoch
NFA-4.2 | | Der Mikroprozessor soll einfach zu erreichen sein. | mittel

## 4.2 Technische Anforderungen

Nr. | Gruppe | Beschreibung | Priorität
TA 1 | Soft- und Hard-ware
TA-1.1 | | IDE - PyCharm und Visual Studio Code | hoch
TA-1.2 | | GUI - PyQt | hoch
TA-1.3 | | Arduino UNO | hoch
TA-1.4 | | Intel RealSense DXXX | hoch

## 4.3 Konstruktive Anforderungen

Nr. | Gruppe | Beschreibung | Priorität
KA 1 | 3D-Konstruktion
KA-1.1 | | Der Halter der Intel Realsense-Kamera soll richtig kalib-riert sein, um einen optimalen Scan zu erzeugen | Hoch
KA-1.2 | | Das Gehäuse muss groß genug sein, um die gesamte Hardware zu halten | Hoch
KA-1.3 | | Die Drehplattform muss sich reibungsfrei drehen | Hoch
KA-1.4 | | Die Drehplattform kann abmontiert werden, um auf die Hardware zugreifen zu können | Hoch
KA-1.5 | | Das Gehäuse muss eine Stromversorgungmöglichkeit anbieten | Hoch
KA-1.6 | | Der Halter der Kamera muss so konstruiert sein, sodass die Montage der Kamera einfach sein sollte | Hoch
KA-1.7 | | Batterien können im Gehäuse sein (Kabellose Stromver-sorgung) | niedrig
KA-1.8 | | Kamerahalter können an-/abmontiert werden | niedrig

## 4.4 Angestrebte Lösungsskizze


Abbildung 1: Konstruktionsskizze


Abbildung 2: GUI Mockup

## 5 Abnahmekriterien

1. Konstruktion als Plattform für das Objekt inklusiver Kamerahalterung sollte gegeben sein.
2. Plattform soll sich um 360° durch die Hardware (Arduino) drehen können.
3. Software soll einen erfolgreichen Scan durchführen können.
4. Software soll eine simple GUI beinhalten.
5. Die GUI soll mindestens einen Button haben zum starten des Scans.
6. Die GUI soll gescanntes Objekt digitalisiert anzeigen können.
7. Der Scanner soll ein Objekt in der Größe einer Kaffeetasse scannen können

## 6 Ansprechpartner für Rückfragen

Name | Vinh Thong Trinh
Funktion | Projektleiter Auftraggeber
E-Mail | S0571062@htw-berlin.de
Telefon | 015786433823
Name | Mert Karadeniz
Funktion | Projektleiter Auftraggeber
E-Mail | S0569367@htw-berlin.de
Telefon | 0176 57931807
Name | Habib Ben Khedher
Funktion | Projektleiter Auftraggeber
E-Mail | S0560734@htw-berlin.de
Telefon | 17623509783
Name | William Eppel
Funktion | Projektleiter Auftraggeber
E-Mail | S0570986@htw-berlin.de
Telefon | 017683395937

## 7 Wer hat was gemacht

Autor | Aufgabe/Kapitel | Anteil
Vinh | Nicht-Funktionale Anforderung, GUI Mockup, Recht- schreibung /Grammatik | 25%
Mert | Einleitung, Funktionale Anforderungen, | 25%
William | Zielsetzung, Funktionale Anforderungen | 25%
Habib | Lösungsskizze, konstruktive Anforderungen | 25%

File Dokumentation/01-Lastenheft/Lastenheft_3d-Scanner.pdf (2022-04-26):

### Lastenheft 3D-Scanner

© HTW Berlin

# Lastenheft

## HTW Berlin 3D-Scanner mit einer Intel RealSense

Autor: | Vinh Thong Trinh, Mert Karadeniz, Habib Ben Khedher, William Eppel
Letzte Änderung: 26. April 2022
Dateiname: | Lastenheft
Version: | 0.2

Copyright

© Mohammad Abuosba

Die Weitergabe, Vervielfältigung oder anderweitige Nutzung dieses Dokumentes oder Teile davon ist unabhängig vom Zweck oder in welcher Form untersagt, es sei denn, die Rechteinhaber/In hat ihre ausdrückliche schriftliche Genehmigung erteilt.

© HTW Berlin

Version Historie:

Version: | Datum: | Verantwortlich | Änderung
0.1 | 12.04.2022 | Alle | Initiale Dokumenterstellung - Lastenheft
0.2 | 18.04.2022 | Alle | Erweiterungen
0.3 | 19.04.2022 | Alle | Endgültiger Entwurf
1.0 | 24.04.2022 | Alle | Finalisierung

© HTW Berlin | Seite 1

## I Inhaltsverzeichnis

II Abbildungsverzeichnis | Fehler! Textmarke nicht definiert.

## II Abbildungsverzeichnis

## 1 Einleitung

Digitalisierung ist ein großer Begriff unter dem man grundlegend die Erfassung von Informationen physischer Objekte in Formate versteht, welche sich zur Verarbeitung oder Speicherung in digitaltechnischen Systemen eignen. Durch Digitalisierung des Objektes vergrößert sich das Spektrum an Möglichkeiten mit dem Objekt um ein Vielfaches.

3D-Scanner sind oft stationär und besitzen mehrere Kameras die auf einen Punkt gerichtet sind. Die Kameras sind keine herkömmlichen Kameras, die Farbinformationen sammeln, sondern Kameras die durch Tiefenbilder Informationen über den Abstand zur Oberfläche des Objekts aufnehmen können. Durch die ermittelten Informationen wird das gescannte Objekt digital rekonstruiert.

## 2 Ausgangsituation

Derzeit werden zum Digitalisieren der Objekte 3D-Scanner genutzt. Die Kosten der Geräte sind für Personen mit durchschnittlichem Einkommen nicht einfach bezahlbar. Außerdem sind die meisten 3D-Scanner sehr groß und immobil. Zudem ist hinzuzufügen, dass die Scanner keine Wartbereitschaft besitzen und ausschließlich vom Hersteller repariert werden können.

Unser Team sollte eine Lösung finden um die Kosten eines derartigen Scanners zu minimieren. Zudem sind die Eigenschaften des Projektes aus Mobilität und Kompaktheit auszuzeichnen. Durch die Kompaktheit, sollte die Technik soweit einsichtig werden, dass Nutzer bei Problemen selber Tatkräftig werden können.

## 3 Zielsetzung

Ziel des Projektes ist es ein Produkt zu schaffen mit dem jeder Interessierte die Option hat diverse Objekte zu digitalisieren. Es soll die Möglichkeit geboten werden die Objekte zu scannen und daraus 3D – Modelle zu erstellen, die anschließend gedruckt werden können.

Das zu scannende Objekt soll auf eine rotierende Plattform platziert werden können. Durch nur eine Kamera soll das Objekt anschließend erfasst werden. Das System soll durch die erfassten Daten ein 3D-Modell erstellen, welches in einem bestimmten Dateityp – Format gespeichert werden soll. Die gespeicherten Daten können anschließend weiterverarbeitet werden um das Objekt beispielsweise zu drucken.

Die Bedienung des Systems soll einfach und intuitiv sein, sodass Nutzer ohne spezifisches Fachwissen dieses benutzen können.

Der Kostenpunkt des Produkts sollte weitestgehend minimiert werden um das Produkt für jeden interessierten erwerbbar zu machen.

## 4 Anforderungen

## 4.1 Software

### 4.1.1 Funktionale Anforderungen

Nr. | Gruppe | Beschreibung | Priorität
FA-1 | Objekt-Plattform
FA-1.1 | Plattform zum Stand und Fixierung des Objekts | hoch
FA-1.2 | Verbindung zur Kamera durch ein Standfuß | wenig
FA-1.3 | Kamerahalterung | mittel
FA-2 | Kamera
FA-2.1 | | Es soll eine einzige Kamera zum Scan benutzt werden | hoch
FA-2.2 | Kamera asynchron einbinden | mittel
FA-2.3 | Kamera sollte automatisch ausgewählt werden bei Ver- bindung des Kabels | hoch
FA-3 | GUI
FA-3.1 | Desktop Anwendung | hoch
FA-3.2 | Einfache Benutzeroberfläche | hoch
FA-3.3 | Übersichtlich und einfache Steuerung | hoch
FA-3.4 | Scan eines Objektes soll durch einen Druck auf einen Button möglich sein | hoch
FA-3.5 | Gescanntes Objekt visualisieren | mittel
FA-3.6 | | Gescanntes Objekt exportieren | hoch
FA-3.7 | | Exportierte Objekte wieder importieren können zum visu-alisieren | mittel
FA-4 | Output
FA-4.1 | | Gescanntes Objekt soll gedruckt werden können | mittel
FA-4.2 | Dateityp: z.B. STL, OBJ, … | hoch

### 4.1.2 Nicht-funktionale Anforderungen

Nr. | Gruppe | Beschreibung | Priorität
NFA 1 | Zuverlässigkeit
NFA-1.1 | | Das System ist sicher und geschützt. | hoch
NFA-1.2 | | Die Hardware muss vor physischen Schäden geschützt werden. | hoch
NFA 2 | Benutzbarkeit
NFA-2.1 | | Das System lässt sich vom Benutzer ohne Handbuch be-dienen. | hoch
NFA-2.2 | | GUI ist einfach zu bedienen. | mittel
NFA 3 | Effizienz
NFA-3.1 | | Der Scan sollte nicht länger als 1 Minuten andauern. | hoch
| | Die Drehplattform soll sich ohne Probleme drehen kön-nen. | hoch
NFA 4 | Wartung
NFA-4.1 | | Quellcode soll gut formatiert und kommentiert sein. | hoch
NFA-4.2 | | Der Mikroprozessor soll einfach zu erreichen sein. | mittel

## 4.2 Technische Anforderungen

Nr. | Gruppe | Beschreibung | Priorität
TA 1 | Soft- und Hard-ware
TA-1.1 | | IDE - PyCharm und Visual Studio Code | hoch
TA-1.2 | | GUI - PyQt | hoch
TA-1.3 | | Arduino UNO | hoch
TA-1.4 | | Intel RealSense DXXX | hoch

## 4.3 Konstruktive Anforderungen

Nr. | Gruppe | Beschreibung | Priorität
KA 1 | 3D-Konstruktion
KA-1.1 | | Der Halter der Intel Realsense-Kamera soll richtig kalib-riert sein, um einen optimalen Scan zu erzeugen | Hoch
KA-1.2 | | Das Gehäuse muss groß genug sein, um die gesamte Hardware zu halten | Hoch
KA-1.3 | | Die Drehplattform muss sich reibungsfrei drehen | Hoch
KA-1.4 | | Die Drehplattform kann abmontiert werden, um auf die Hardware zugreifen zu können | Hoch
KA-1.5 | | Das Gehäuse muss eine Stromversorgungmöglichkeit anbieten | Hoch
KA-1.6 | | Der Halter der Kamera muss so konstruiert sein, sodass die Montage der Kamera einfach sein sollte | Hoch
KA-1.7 | | Batterien können im Gehäuse sein (Kabellose Stromver-sorgung) | niedrig
KA-1.8 | | Kamerahalter können an-/abmontiert werden | niedrig

## 4.4 Angestrebte Lösungsskizze


Abbildung 1: Konstruktionsskizze


Abbildung 2: GUI Mockup

## 5 Abnahmekriterien

1. Konstruktion als Plattform für das Objekt inklusiver Kamerahalterung sollte gegeben sein.
2. Plattform soll sich um 360° durch die Hardware (Arduino) drehen können.
3. Software soll einen erfolgreichen Scan durchführen können.
4. Software soll eine simple GUI beinhalten.
5. Die GUI soll mindestens einen Button haben zum starten des Scans.
6. Die GUI soll gescanntes Objekt digitalisiert anzeigen können.
7. Der Scanner soll ein Objekt in der Größe einer Kaffeetasse scannen können

## 6 Ansprechpartner für Rückfragen

Name | Vinh Thong Trinh
Funktion | Projektleiter Auftraggeber
E-Mail | S0571062@htw-berlin.de
Telefon | 015786433823
Name | Mert Karadeniz
Funktion | Projektleiter Auftraggeber
E-Mail | S0569367@htw-berlin.de
Telefon | 0176 57931807
Name | Habib Ben Khedher
Funktion | Projektleiter Auftraggeber
E-Mail | S0560734@htw-berlin.de
Telefon | 17623509783
Name | William Eppel
Funktion | Projektleiter Auftraggeber
E-Mail | S0570986@htw-berlin.de
Telefon | 017683395937

## 7 Wer hat was gemacht

Autor | Aufgabe/Kapitel | Anteil
Vinh | Nicht-Funktionale Anforderung, GUI Mockup, Recht- schreibung /Grammatik | 25%
Mert | Einleitung, Funktionale Anforderungen, | 25%
William | Zielsetzung, Funktionale Anforderungen | 25%
Habib | Lösungsskizze, konstruktive Anforderungen | 25%

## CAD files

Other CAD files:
Konstruktion/3D_Scanner_Prototyp.iam
Konstruktion/Drehplatform_prototyp.ipt
Konstruktion/Gehaeuse_prototyp.ipt
Konstruktion/Kamerahalter_prototyp.ipt
Konstruktion/OldVersions/3D_Scanner_Prototyp.0003.iam
Konstruktion/Prototyp 2/Kamerahalter_II.ipt
Konstruktion/Prototyp 2/OldVersions/gehäuse_scan.0002.ipt
Konstruktion/Prototyp 2/bearing_holder.ipt
Konstruktion/Prototyp 2/gehäuse_scan.ipt
Konstruktion/Prototyp 2/platform_scan.ipt
Konstruktion/Prototyp 2/zahnrad.ipt

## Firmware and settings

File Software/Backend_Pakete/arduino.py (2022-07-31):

import serial
import time

class Arduino():

    def __init__(self, comPort, baudRate, timeout):
        self.comPort = comPort
        self.baudRate = baudRate
        self.timeout = timeout
        self.serPort = serial.Serial(self.comPort, self.baudRate, timeout=self.timeout)
        time.sleep(2)
        self.curstep = 0

#rotationsbefehl an arduino
    def rotieren(self, steps):
        self.steps = steps
        self.neg = int(self.steps < 0)
        if self.neg:
            self.steps = -self.steps
        self.stepsString = str(self.steps)
        self.serPort.write([self.neg])
        for i in range(5 - len(self.stepsString)):
            self.serPort.write([0])
        for i in range(len(self.stepsString)):
            self.serPort.write([int(self.stepsString[i])])

#warten auf ende der rotation
    def warteAufRotation(self):
        while True:
            self.data = str(self.serPort.readline())
            if self.data != "b''":
                self.curstep += self.steps
                if int(str(self.data)[2:len(self.data) - 1]) != self.steps:
                    self.close()
                    raise Exception("The Arduino returned the wrong number of steps!")
                break

#gibt den winkel der ROtation zurück
    def winkel(self):
        self.gearRatio = 6
        self.currentAngle = ((self.curstep * 360) / 2048) / self.gearRatio
        return self.currentAngle

    def close(self):
        self.serPort.close()

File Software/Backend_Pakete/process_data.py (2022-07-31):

import open3d as o3d #pip install open3d
import numpy as np #pip install numpy


class ProcessData():
   


    def __init__(self):

        self.boundingBox = o3d.geometry.AxisAlignedBoundingBox((-0.13, -0.13, 0), (0.13, 0.13, 0.2))

        self.hauptPointCloud = o3d.geometry.PointCloud()

        self.dtr = np.pi / 180
        self.distance = 0.258


#konvertieren der aufgenommenen Daten in Punktwolken

    def konvertieren(self, angle, depth_image, color_image, intrinsic):

        print(angle)

        self.winkel = angle

        self.depth_frame_open3d = o3d.geometry.Image(depth_image)
        self.color_frame_open3d = o3d.geometry.Image(color_image)

        self.rgbd_image = o3d.geometry.RGBDImage.create_from_color_and_depth(self.color_frame_open3d,
                                                                             self.depth_frame_open3d,
                                                                             convert_rgb_to_intensity=False)


        self.pointCloud = o3d.geometry.PointCloud.create_from_rgbd_image(self.rgbd_image, intrinsic)


        self.pointCloud.estimate_normals(search_param=o3d.geometry.KDTreeSearchParamHybrid(radius=0.1, max_nn=30))
        self.pointCloud.orient_normals_towards_camera_location(camera_location=np.array([0., 0., 0.]))
        self.getKameraPos()
        self.rtMatrix()
        self.pointCloud.rotate(self.R, (0, 0, 0))
        self.pointCloud.translate((self.x, self.y, self.z))
        self.pointCloud = self.pointCloud.crop(self.boundingBox)
        self.pointCloud, self.ind = self.pointCloud.remove_statistical_outlier(nb_neighbors=100, std_ratio=2)
        self.hauptPointCloud = self.hauptPointCloud + self.pointCloud


#Punktwolke zurückgeben
    def getPointcloud(self):
        return self.hauptPointCloud



    def getKameraPos(self):
        self.x = np.sin(self.winkel * self.dtr) * self.distance - np.cos(self.winkel * self.dtr) * 0.035
        self.y = -np.cos(self.winkel * self.dtr) * self.distance - np.sin(self.winkel * self.dtr) * 0.035
        self.z = 0.165
        self.o = self.winkel
        self.a = 112.5
        self.t = 0

    def rtMatrix(self):
        self.o = self.o * self.dtr
        self.a = (-self.a) * self.dtr
        self.t = self.t * self.dtr
        self.R = [[np.cos(self.o) * np.cos(self.t) - np.cos(self.a) * np.sin(self.o) * np.sin(self.t),
                   -np.cos(self.o) * np.sin(self.t) - np.cos(self.a) * np.cos(self.t) * np.sin(self.o),
                   np.sin(self.o) * np.sin(self.a)],
                  [np.cos(self.t) * np.sin(self.o) + np.cos(self.o) * np.cos(self.a) * np.sin(self.t),
                   np.cos(self.o) * np.cos(self.a) * np.cos(self.t) - np.sin(self.o) * np.sin(self.t),
                   -np.cos(self.o) * np.sin(self.a)],
                  [np.sin(self.a) * np.sin(self.t), np.cos(self.t) * np.sin(self.a), np.cos(self.a)]]

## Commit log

2022-05-30 Upload New File
    Bewertung und Kommentierung Abgabe 2
2022-06-11 Bauteile von 3D-Scanner
    [3D_Scanner_Prototyp.iam, Drehplatform_prototyp.ipt, Gehaeuse_prototyp.ipt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]
2022-06-12 änderung 3D-Scanner
    [3D_Scanner_Prototyp.0003.iam, 3D_Scanner_Prototyp.iam]
2022-07-05 added arduino_Portcheck function
2022-07-05 minor fix arduino_Portcheck
2022-07-06 Serielle Kommunikation bei der Arduinocode im plementiert
2022-07-06 neue Prototyp hinzugefügt
    [Kamerahalter_II.ipt, bearing_holder.ipt, gehäuse_scan.ipt]
2022-07-06 removed import pcd, stl
2022-07-06 data dir
    [cube.stl]
2022-07-07 GUI Update, requirements update
    [cube.stl]
2022-07-07 kontruktion update
    [platform_scan.ipt, zahnrad.ipt]
2022-07-10 Änderung kontruktion
    [gehäuse_scan.0002.ipt, gehäuse_scan.ipt]
2022-07-27 button update, setting page update, disable button added
2022-07-28 cam+arduino check added
2022-07-31 new Arduino code
